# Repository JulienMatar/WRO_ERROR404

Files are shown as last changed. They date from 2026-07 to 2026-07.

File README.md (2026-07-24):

# Content
# t-photos 
contains 2 photos of the team (an official one and one funny photo with all team members)
# v-photos 
contains 6 photos of the vehicle (from every side, from top and bottom)
# video
contains the video.md file with the link to a video where driving demonstration exists
# src 
contains code of control software for all components which were programmed to participate in the competition
# other 
is for other files which can be used to understand how to prepare the vehicle for the competition. It may include documentation how to connect to a SBC/SBM and upload files there, datasets, hardware specifications, communication protocols descriptions etc. If there is nothing to add to this location, the directory can be removed.
# Introduction
This part must be filled by participants with the technical clarifications about the code: which modules the code consists of, how they are related to the electromechanical components of the vehicle, and what is the process to build/compile/upload the code to the vehicle’s controllers.
# WRO Future Engineers 2026 — Team ERROR404

**Team members:** Julien Matar, Ali Kholindy

**Category:** WRO Future Engineers — Self-Driving Cars Challenge, Season 2026

This repository contains the engineering documentation, source code, electromechanical
schematics, and vehicle media for our self-driving vehicle competing in the WRO Future
Engineers category.

---

## Content

| Folder | Contents |
|---|---|
| `t-photos/` | Team photos (official + informal) |
| `v-photos/` | Vehicle photos (all sides, top, bottom) |
| `video/` | `video.md` with links to autonomous driving demonstration videos |
| `schemes/` | Wiring/electrical diagrams of all electromechanical components |
| `src/` | Control software for the Raspberry Pi and Arduino Uno |
| `models/` | 3D-printable / CNC files for chassis, steering, and gearbox components |
| `other/` | Supporting documentation, datasets, and setup instructions |

---

## 1. Mobility and Mechanical Design

Our vehicle is a 4-wheeled car with **Ackermann steering** at the front axle and a single
**driving motor** connected to the rear axle through a gearbox, satisfying the WRO
requirement that driving wheels be mechanically linked (no independent per-side motors /
electronic differential).

**Drivetrain:**
- Drive motor: **25GA-370 DC gear motor**, driving the rear axle through a gearbox.
- Steering: a dedicated **servo motor** actuates the front axle through an Ackermann
  linkage, giving each front wheel a slightly different turning radius — closer to how a
  real car steers than a simple single-pivot mechanism, which reduces tire scrub in tight
  corners.

**Why Ackermann + single rear drive motor:**
We chose a single drive motor over a dual-motor differential-style setup because the WRO
rules explicitly disqualify differential wheeled bases with one motor per side. Beyond
compliance, a single motor through a gearbox is mechanically simpler to keep aligned and
reduces the number of things that can desync during a run (e.g. two motors drifting out
of sync under slightly different loads).

`[FILL IN: gear ratio you used on the 25GA-370 gearbox, and why — e.g. did you test more
than one ratio? What tradeoff did you observe between top speed and torque/turning
control? Include any measured lap-time or stability differences.]`

**Chassis:**
The chassis and steering linkage are 3D-printed (STL files in `models/chassis/` and
`models/Steering/`), keeping the vehicle within the WRO limits of 300×200 mm footprint,
300 mm height, and 1.5 kg total weight.

The 25GA-370 drive motor (200 RPM variant) came bundled with our chassis kit rather than being independently selected from a range of gear ratios. During testing, we found the vehicle's top speed to be a limiting factor rather than torque — the car did not struggle with load or cornering, but felt slower than we'd like on the straight sections of the track. This suggests that a higher-RPM variant (e.g. 300 RPM, which uses a lower internal gear ratio and sacrifices some torque for speed) could improve lap times, since our track sections do not appear to demand more torque than the 200 RPM motor already provides. We are noting this as a potential upgrade for future iterations rather than a change made this season

## 2. Power and Sensor Architecture

**Power system:**
Two 11.1V LiPo batteries are wired in **parallel** (not series) behind a single main
power switch on the combined positive lead — satisfying the WRO requirement for one
switch to power on the vehicle. From there, power splits into two independent branches:

1. A DC-DC buck converter (rated for up to 36V input, well above our battery voltage,
   giving headroom against sag under load) steps the pack voltage down to a **regulated
   5V** logic rail, powering the Raspberry Pi, Arduino Uno, and servo.
2. The **L9110 dual-channel H-bridge** motor driver is fed directly from the 11.1V battery
   rail to drive the 25GA-370 drive motor at full torque, independent of the logic supply.

Separating the motor supply from the logic supply protects the Pi and Arduino from voltage
dips caused by motor stall current or back-EMF, which is a common failure mode if a motor
driver and logic share a single unregulated rail.

The voltage overall from the batteries drops approximately 0.3-0.8V when the motor is spinning, which is normal because one battery is supplying the whole robot at a time, while supplying the buck converter for the stable 5V for the microcontrollers and sensors, even with this voltage drop, its not significant to a point where the robot will slow down/ slug/ or even lag when driving,nor is affecting the output of the buck converter, one 12V LiPo battery is enough to supply for the whole robot, because we also have a backup we can switch freely and easily by simply switching the T plug from a battery to another,

**Start button:**
A separate momentary push button acts as the WRO-compliant Start button (distinct from
the main power switch), matching the required "one switch to power on, one button to
start the program" sequence.

**Sensors:**

| Sensor | Purpose |
|---|---|
| Raspberry Pi Camera v2 (5MP) | Primary vision input — lane detection, traffic sign (pillar) color and position detection |
| TCS3200 color sensor | Auxiliary color detection (e.g. surface/line color cues, or close-range pillar color confirmation) |
| 4–6 ultrasonic sensors | Distance/wall/obstacle sensing around the vehicle perimeter for wall-following and collision avoidance |

we have used 3 ultrasonic sensors for the front side of the robot, to detect distance from all sides while driving in order to avoid all obstacles and not hit one single pillar or wall, and one ultrasonic sensor from the back to assist with the parallel parking in order to prevent the car from hitting the back wall,
We also used the camera to only detect the pillars color with a specific code uploaded to the rpi to let the camera know if the pillar is green or red, and the color sensor module is for the lines on the ground ( orange and blue) in order to count the lines to know how many laps were already accomplished because the rpi that we chose is budget friendly, but not powerful enough to handle a powerful AI to do all of this, we priorotized sensor integration and color detection.
Lastly, we tuned the color detection detection code using the CMYK and RGB values given in the PDF

---

## 3. Software Architecture and Obstacle Strategy

Control is split across two controllers by responsibility:

- **Raspberry Pi 3B+** — runs the vision pipeline (camera capture and image processing)
  and high-level decision-making: detecting the lane boundaries, detecting and
  classifying red/green traffic pillars, and deciding which side to pass them on per the
  WRO rule (red pillar → pass on the right, green pillar → pass on the left).
- **Arduino Uno** — handles real-time, low-latency execution: driving the L9110 motor
  driver, actuating the steering servo, and polling the ultrasonic sensors and TCS3200
  color sensor. It receives high-level commands (e.g. target heading, speed) from the Pi
  over a serial link and executes them continuously between updates.

This split exists because vision processing on the Pi is not guaranteed to run at a fixed,
low-latency interval, while motor and servo control benefit from a tight, predictable loop
that only a dedicated microcontroller can reliably provide.

Two pillars appearing in the same section is not yet handled by our current logic, this is planned as future work rather than something implemented this season.
The Arduino determines it has cleared a pillar once the relevant ultrasonic sensor no longer detects it within range, at which point the steering offset resets back to center (wall-equidistant) driving.

---

## 4. Systems Thinking and Engineering Decisions

Key constraints we designed around:
- **Weight and size limits** (1.5 kg, 300×200×300 mm) — influencing our choice of
  lightweight 3D-printed chassis parts over heavier off-the-shelf alternatives.
- **Compute split** — offloading real-time motor/servo control to the Arduino so that
  camera processing delays on the Pi never translate into jerky or delayed motor response.
- **Power isolation** — separating the motor supply from the logic supply to avoid
  brownouts on the Pi/Arduino during motor stall or direction changes.

A key tradeoff in our sensor architecture was splitting color-detection tasks between the camera and the TCS3200 rather than relying on the camera alone. Our Raspberry Pi 3B+ is not powerful enough to reliably run full real-time computer vision for both pillar detection and ground-line/lap counting simultaneously, so we assigned each task to the sensor best suited for it: the camera for pillar color/position (where a wider field of view matters), and the TCS3200 for ground-line detection (a simpler, close-range color read that doesn't need a full image pipeline). This let us keep both detection tasks reliable without overloading the Pi's processing budget.
One failure mode we identified: if the wall-centering steering correction is too weak, the vehicle drifts into a wall during cornering rather than actively correcting (see Section 3 for the fix — we increased correction sensitivity to resolve this).
Our design changed iteratively during testing: version 1 of the wall-centering logic used a weak steering correction, which caused the vehicle to drift into walls on corners. After identifying this, we increased the correction's sensitivity to the left/right ultrasonic distance difference, which resolved the drift without introducing oscillation

## 5. Reproducibility and Build Instructions

### Repository structure
- `src/arduino/` — Arduino Uno sketch(es) controlling the L9110 motor driver, steering
  servo, ultrasonic sensors, and TCS3200 color sensor.
- `src/pi/` — Raspberry Pi Python code for camera capture, image processing, and
  high-level driving logic.
- `schemes/` — Wiring diagrams showing how the batteries, buck converter, L9110, motor,
  servo, sensors, Pi, and Arduino are all connected.
- `models/` — STL files for 3D-printed chassis and steering components.

### Build / compile / upload process

1. **Arduino side:**
   - Open `src/arduino/<sketch_name>.ino` in the Arduino IDE (or use `arduino-cli`).
   - Select board: **Arduino Uno**.
   - Connect via USB and upload.

2. **Raspberry Pi side:**
   - Copy the contents of `src/pi/` to the Raspberry Pi (e.g. via `scp`, or clone this
     repository directly on the Pi).
   - Install dependencies: `pip install -r requirements.txt`
   - Run the main control script, e.g. `python3 main.py`.
   - Currently, the control script is launched manually via terminal/SSH rather than auto-starting on boot. Setting this up as a systemd service (or an rc.local       entry) so the vehicle powers on directly into the WRO-required "waiting for start button" state is planned as a next step before competition, since manual         terminal launching would not satisfy the WRO starting procedure requirement.

3. Confirm the serial port name and baud rate match between the Pi script and the
   Arduino sketch before running.
The Raspberry Pi code currently uses opencv-python (cv2) for camera capture and pillar color/image processing, and numpy for underlying array/image data handling. The Arduino sketch uses standard built-in libraries for servo control and digital I/O; no external Arduino libraries are required beyond the standard toolchain.
---

## Wiring Overview (see `schemes/` for full diagrams)

- 2× 11.1V LiPo batteries → parallel → single main power switch → splits to:
  - DC-DC buck converter (36V-rated input, set to 5V output) → Raspberry Pi, Arduino,
    servo logic
  - L9110 motor driver (direct 11.1V) → 25GA-370 drive motor
- Push button (separate from main switch) → WRO-compliant start trigger
- Arduino Uno ↔ Raspberry Pi 3B+ via serial (USB)
- Arduino Uno ↔ 4–6 ultrasonic sensors, TCS3200 color sensor, steering servo, L9110
- Raspberry Pi 3B+ ↔ Camera v2 (5MP) via CSI ribbon cable

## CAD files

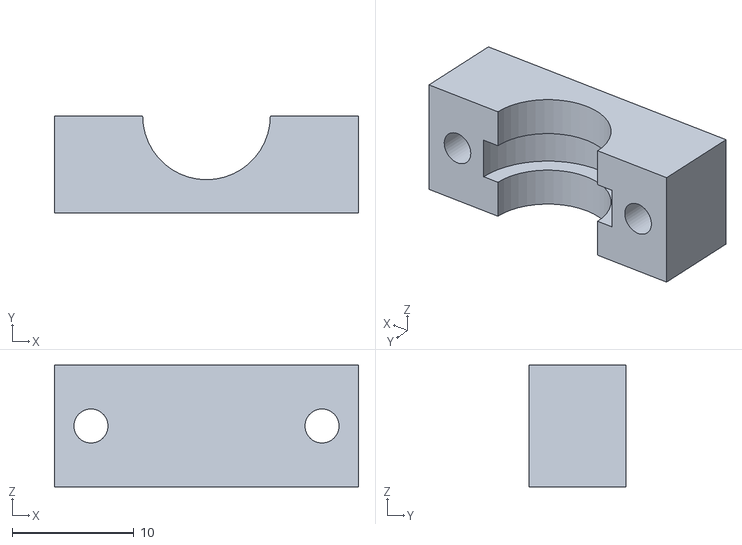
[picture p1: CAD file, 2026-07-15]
models/chassis/rear_Axle_bracket_tierod.STL
25.0 x 8.00 x 10.0

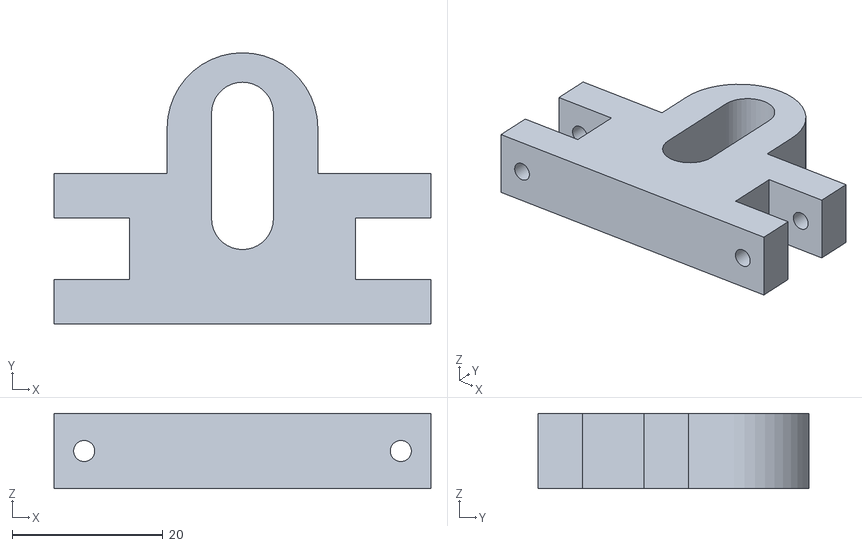
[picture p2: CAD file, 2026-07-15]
models/Steering/Ackerman_5.STL
50.0 x 36.0 x 10.0

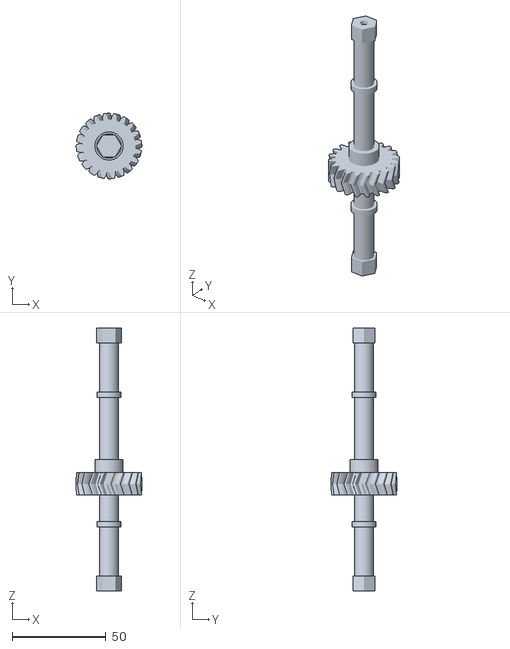
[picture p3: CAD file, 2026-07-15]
models/chassis/axle_with_gear_v3.stl
34.9 x 34.9 x 140.0

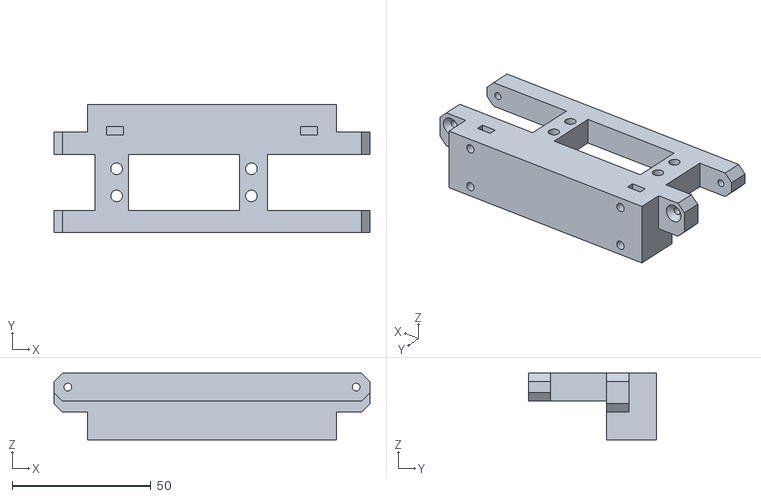
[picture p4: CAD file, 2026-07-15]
models/Steering/Ackermann_1.STL
114.0 x 46.2 x 24.0

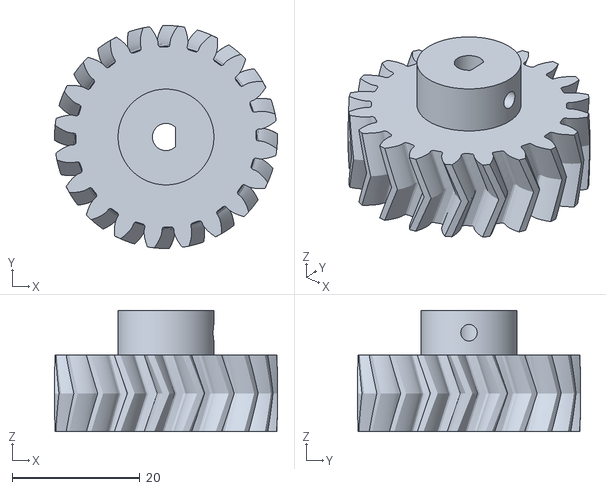
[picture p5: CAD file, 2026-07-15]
models/chassis/pinion_20T_GA25.stl
34.9 x 34.9 x 19.0

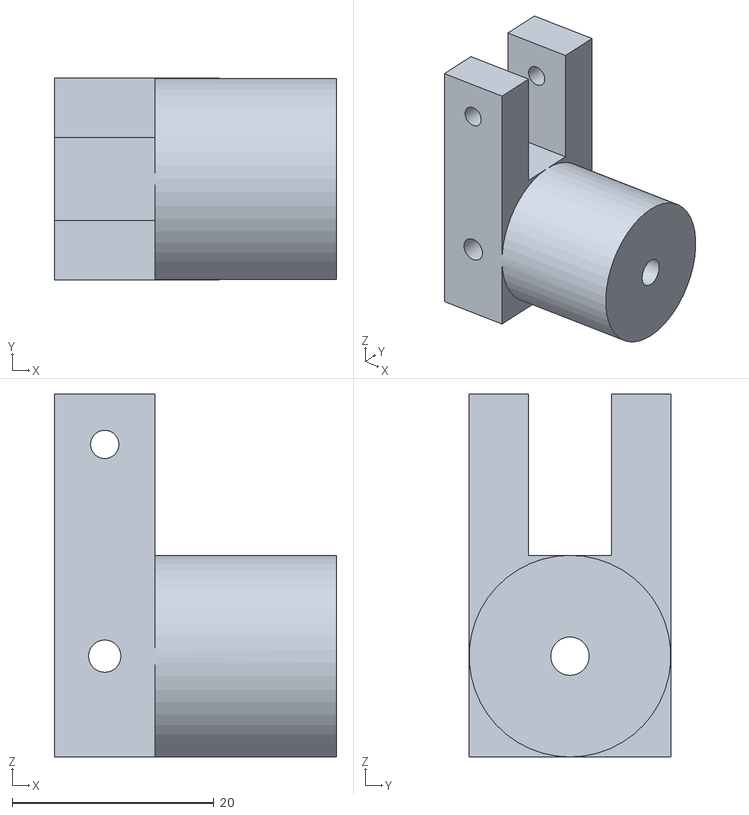
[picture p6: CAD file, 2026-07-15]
models/Steering/Ackermann_4X2.STL
28.0 x 20.0 x 36.0

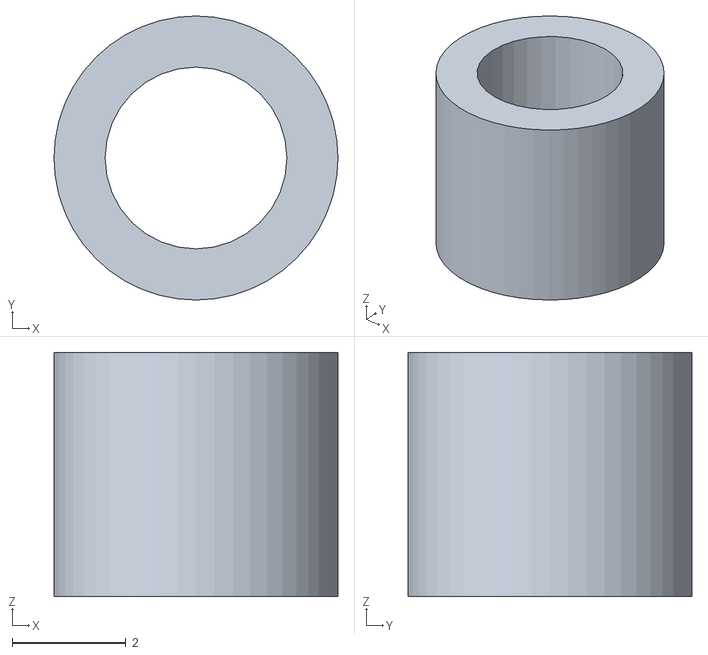
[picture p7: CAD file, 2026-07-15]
models/chassis/idler_spacer.stl
5.00 x 5.00 x 4.30

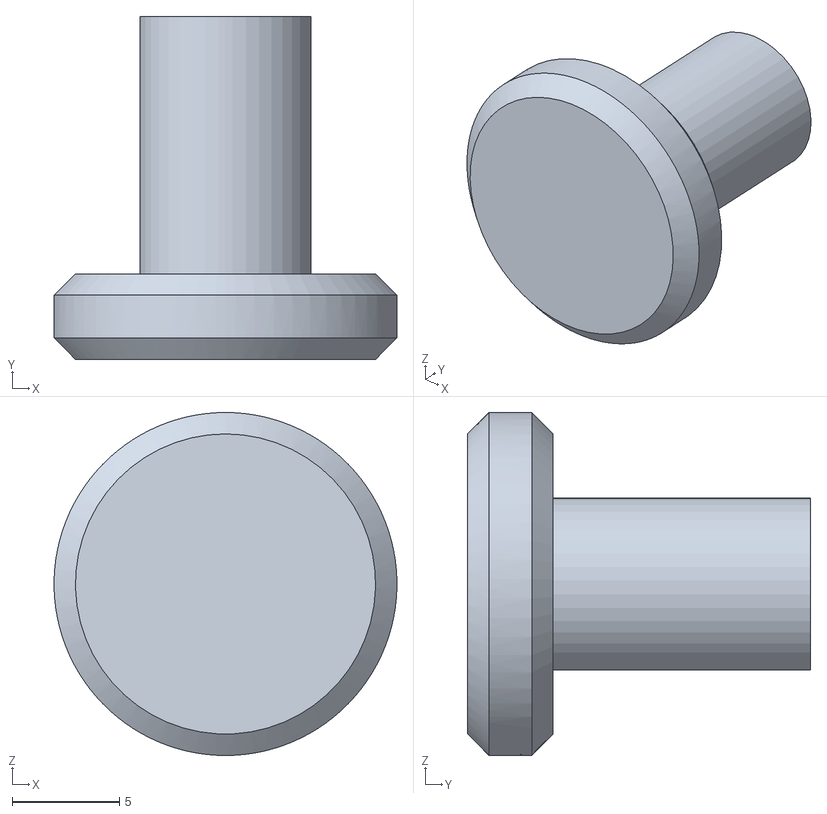
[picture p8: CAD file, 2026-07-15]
models/Steering/Ackermann_2.STL
16.0 x 16.0 x 16.0

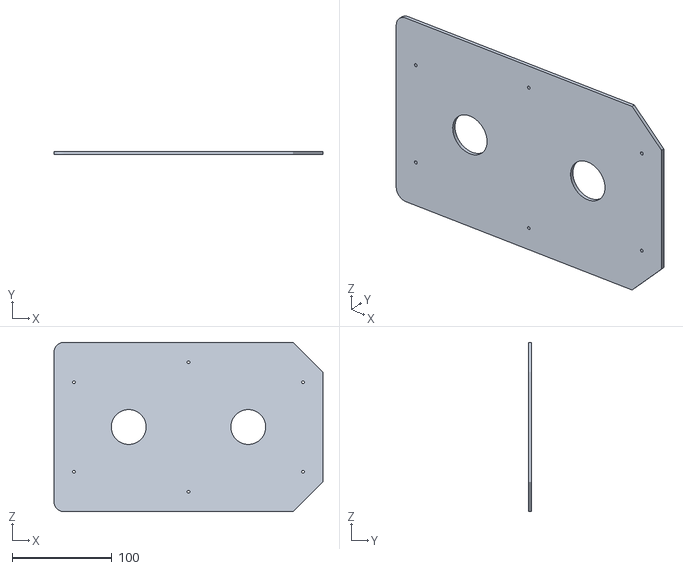
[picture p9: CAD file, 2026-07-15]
models/chassis/chassisTop.STL
270.0 x 3.00 x 170.0

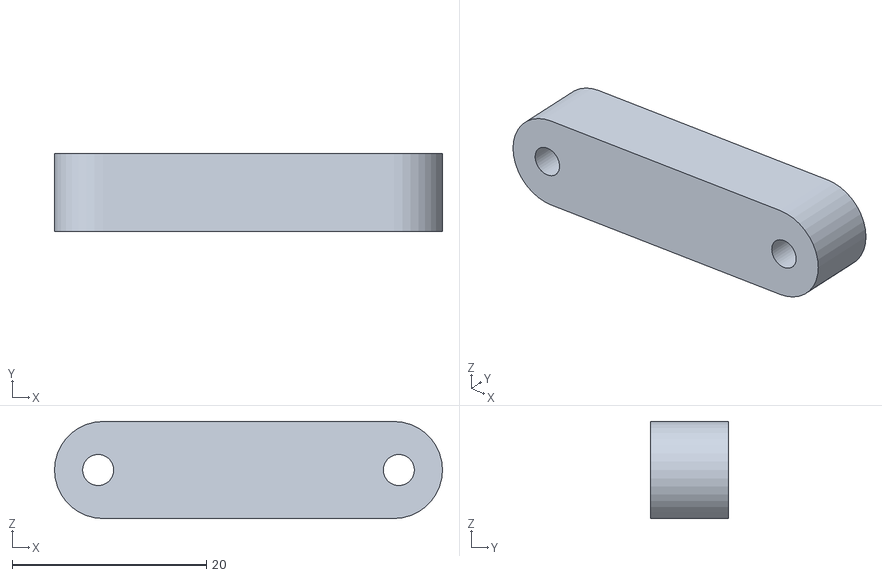
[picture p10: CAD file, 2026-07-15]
models/Steering/Ackermann_3X2.STL
40.0 x 8.00 x 10.0

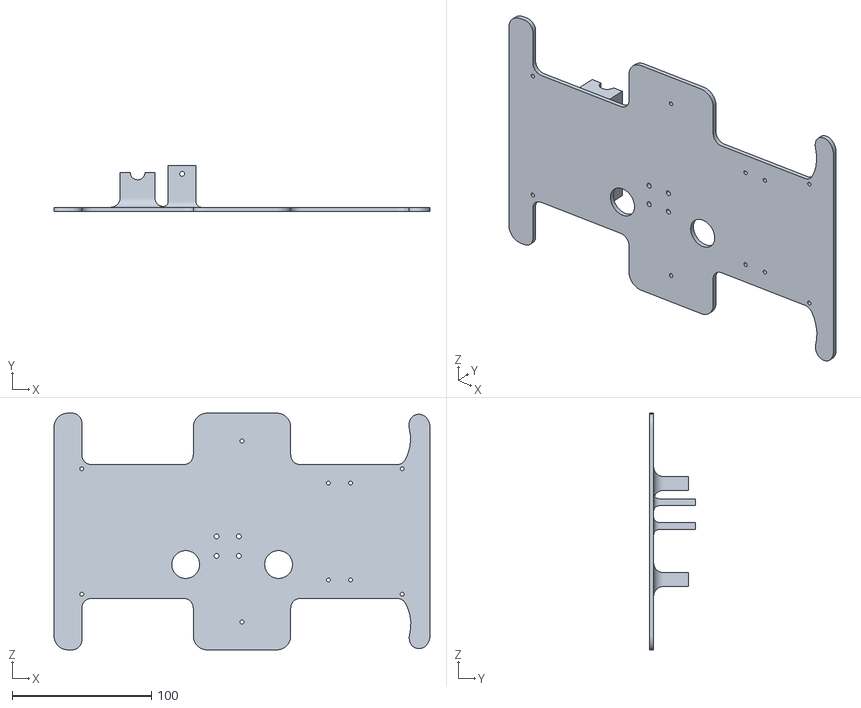
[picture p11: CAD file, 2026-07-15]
models/chassis/chassis.STL
270.0 x 33.0 x 170.0

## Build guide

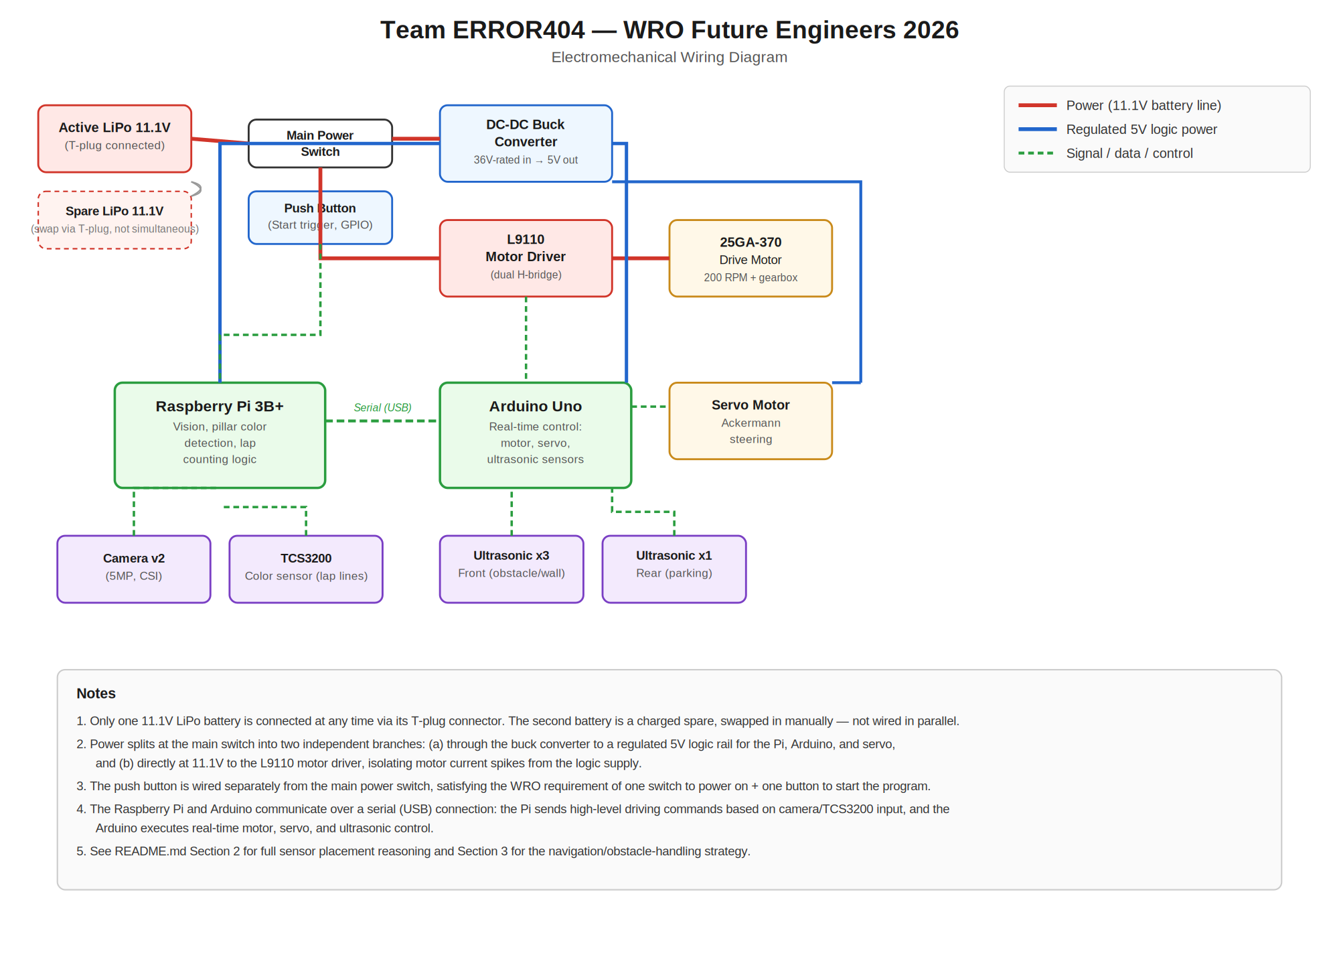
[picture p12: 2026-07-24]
schemes/wiring_diagram.png

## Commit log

2026-07-15 README edit
    Updated README to include detailed engineering materials and content structure for the WRO Future Engineers competition.
2026-07-15 Added the chassis design
    these files show the chassis designed used as an STL file in order to 3D print the car parts.
    [axle_with_gear_v3.stl, chassis.STL, chassisTop.STL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]
2026-07-15 added ackermann steering STL files
    these files represent the steering mechanism used for the car uploaded as STL files
    [Ackerman_5.STL, Ackermann_1.STL, Ackermann_2.STL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]
